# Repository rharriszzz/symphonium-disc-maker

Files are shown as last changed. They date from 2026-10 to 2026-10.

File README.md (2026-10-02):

# symphonium-disc-maker

Generate **exact SVG and DXF disc geometry** for the 20-note plastic-disc
mechanism used in a Mr. Christmas Animated Holiday Symphonium
(model 140-24021), plus simple printable/cuttable label sheets.

This repository begins as a reverse-engineering and arranging project.
The geometry is based on measurements, a 600 dpi scan of an original
*Unchained Melody* disc, a recording of the mechanism, and direct measurements
of the comb/plucker assembly.

## Status

**Experimental. Verify dimensions before paying for manufacturing.**

The most important current working values are:

- disc diameter: **7.000 in**
- original disc thickness: **0.020 in**
- prototype center hole: **0.200 in** (rounded from clear-edge scan fits)
- trusted metal center post: **0.1925 in**
- drive holes: **143**
- nominal drive-hole size: **0.100 in radial × 0.090 in tangential**
- drive-hole center radius: **3.373 in**
- note tracks: **20**
- note-hole diameter: **0.116 in**
- innermost track center radius: **0.94968 in**
- track pitch: **0.117921 in**
- provisional scale, inner to outer: **C4 through A6, white notes only**
- measured revolution time: about **28.126 s**

All of these live in `geometry.json` so they can be revised without changing code.

## Repository layout

```text
geometry.json                         measured machine geometry
examples/pachelbel_sampler.json      20-note, one-strike-per-tine sampler loop
examples/minimal_example.json        smallest arrangement example
src/symphonium_disc_maker/
    arrangement.py                   load/validate note events
    geometry.py                      track/note mapping
    svg.py                           exact printable/vector disc
    dxf.py                           manufacturing DXF
    labels.py                        label sheet generator
    cli.py                           command-line interface
tests/                               geometry and file-generation tests
docs/MEASUREMENTS.md                 provenance and open questions
```

## Installation

From the repository root:

```bash
python -m venv .venv

# Windows PowerShell
.venv\Scripts\Activate.ps1

# bash / macOS / Linux / WSL
source .venv/bin/activate

pip install -e .
```

## Make the Pachelbel sampler disc

Validate:

```bash
symphonium-disc validate examples/pachelbel_sampler.json
```

Generate an annotated SVG:

```bash
symphonium-disc svg examples/pachelbel_sampler.json \
  -o output/pachelbel_sampler.svg
```

Generate a manufacturing DXF in millimeters:

```bash
symphonium-disc dxf examples/pachelbel_sampler.json \
  -o output/pachelbel_sampler.dxf
```

The DXF contains only cut geometry: outside circle, center hole, 143 drive
holes, and music-note holes.

## Arrangement format

```json
{
  "title": "Example",
  "revolution_seconds": 28.126,
  "events": [
    {"time_seconds": 0.0, "note": "C5"},
    {"time_seconds": 0.7, "note": "E5"},
    {"time_seconds": 1.4, "note": "G5"}
  ]
}
```

`track` may be supplied instead of `note`.

The disc encodes **note onset**, not conventional note duration.

SVG and DXF show the **printed/top face**. Chronological holes proceed
clockwise around that stationary design, matching the reported counterclockwise
rotation during playback. Positive polar angles are counterclockwise from
the right (+X). `--start-angle` sets an arbitrary layout phase (default 230°),
not a measured reader angle. See the
[rotation follow-up](docs/CODEX_FOLLOWUP_ROTATION_CENTERPOST.md) for the evidence.

## Labels

Generate an 8.5 × 11 inch SVG sheet containing 20 circular labels:

```bash
symphonium-disc labels \
  --title "PACHELBEL" \
  --subtitle "Canon — sampler disc" \
  -o output/pachelbel_labels.svg
```

The label output is intended for a print-and-cut device such as a
BossKut Gazelle, Silhouette, Cricut, or similar machine.

The default 1.50-inch center label stays clear of the music holes. Use
`--mode print` for text only and `--mode cut` for circles only; `combined`
is the default paper fitting preview. The CLI checks the label diameter
against the innermost music holes and reads the center hole from `geometry.json`.
See [the label workflow and Gazelle findings](docs/LABELS.md) for examples,
alignment limitations, and the CUTOK driver investigation.
The [latest conversation discoveries](docs/CHATGPT_LATEST_DISCOVERIES.md)
confirm the disk geometry and update the Windows 11 / Mac Gazelle setup path.

A [printable fitting PDF](prototype_pack/label_fit_test.pdf) is ready for a
plain-paper test at 100% scale. It has a one-inch calibration ruler and
1.50-inch circles. The [prototype pack](prototype_pack/README.md) also contains
the cutting DXF and supplier drafts. These files are prepared for review;
supplier quotes and physical fit are still pending.
Separate [Xometry](supplier_packages/xometry_quote.zip) and
[SendCutSend](supplier_packages/sendcutsend_quote.zip) quote ZIPs now package
the cutting DXF, a dimensioned reference PDF and each company's request.
See [the delivery instructions](supplier_packages/README.md).
For a step-by-step plan with clickable links and Windows folder paths, read
`docs/NEXT_STEPS.md` or run `cat docs/NEXT_STEPS.md` in the repository terminal.

To make PDF labels, install `pip install -e '.[print]'` and choose a `.pdf`
output filename. Add `--calibration` for a paper fitting test. SVG and DXF
exporting still need no third-party runtime dependencies.

## Manufacturing notes

For services such as SendCutSend or Xometry:

- use the generated **DXF**;
- keep manufacturing artwork separate from labels and annotations;
- upload at **1:1 scale**;
- this project defaults to **millimeters** in DXF to avoid unit ambiguity;
- check quoted minimum feature size and material availability before ordering.

The original disc is approximately 0.020 inch thick. Material choice remains
an active experiment.

See [the prototype ordering notes](docs/ORDERING.md) for current supplier
options, draft inquiries, and the measurements to resolve before paying.
The prototype center-hole nominal is now 0.200 inch, rounded from approximately
0.198-inch clear-edge scan fits and consistent with the less certain 0.1995-inch
plastic-hole reading. The trusted metal post measures 0.1925 inch.
The nominal hole gives 0.0075 inch diametral clearance;
supplier tolerances and finished fit need checking. The corrected drive ring
has bridges as narrow as 0.05602 inch. Supplier tolerances and material behavior
still need confirmation.

The [conversation handoff](docs/CODEX_HANDOFF.md) supplies the scan-derived
drive-hole orientation. Both exporters rotate the openings around the ring.
The first material candidates are Xometry's 0.020-inch clear PETG and
SendCutSend's 0.030-inch clear polypropylene; their playback behavior remains
to be tested.

The [original scan and audio check](docs/REFERENCE_CHECK.md) independently
supports the drive-hole orientation and playback direction. It includes a
reproducible analysis script, a calibrated overlay, and detected-hole tables.
Opposite-quadrant edge comparisons distinguish scanner shadows from the
slightly rectangular openings and supply the current prototype dimensions.
Optional analysis dependencies can be installed with `pip install -e '.[analysis]'`.

The follow-up checks align all 143 drive openings and compare 22 starting
pitches. The rectangular shape and global C4–G6 occupied-track map hold across
the independent checks; track 20's A6 remains inferred until the sampler plays it.

## Next steps

- test the scan-derived radial and tangential drive-hole sizes on a prototype;
- cut the 20-note Pachelbel sampler;
- record isolated real tines;
- refine the playable pitch map and rotation timing;
- add MIDI/MusicXML import and arranging helpers;
- add disk PDF previews;
- add optional registration marks for print-and-cut label workflows.

## License

MIT.

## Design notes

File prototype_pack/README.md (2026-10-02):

# Pachelbel prototype pack

Prepared for a first fit/playback test. No quote or order has been submitted.
The same cutting geometry is intended for both supplier/material experiments.

## Files to use

- **`pachelbel_cut_mm.dxf`**: attach only this file for cutting. Confirm the
  quote preview shows a 177.800 mm outside diameter, 143 rotating rectangular
  drive openings and 20 round music holes. It contains 22 circles and 572 lines.
- `pachelbel_preview.svg`: annotated top-face inspection preview; guides and
  note names are not cutting geometry. Later attacks proceed clockwise.
- `xometry_inquiry.txt` and `sendcutsend_inquiry.txt`: supplier-specific drafts
  to review with the DXF. Quantity one each is proposed; price and fit are unknown.
- **`label_fit_test.pdf`**: print on plain US Letter paper at actual size / 100%,
  disabling Fit and Shrink. Measure the one-inch ruler and a 1.50-inch circle,
  then hand-cut one label and its 0.200-inch center opening. Check it on the original
  disk before using adhesive stock. This test can proceed without a cutter.
- `labels_print.pdf` and `labels_print.svg`: printing artwork without cut lines.
- `labels_cut.svg`: outer circles and center holes for cutter import.
- `labels_combined.svg`: artwork and outlines for inspection. All label files
  share the same 20-label layout; automatic print-to-cut registration is not provided.
- `recording_sequence.csv`: one attack per track, in time order, with expected
  pitches to test. Align a recorded cycle by its opening C6 attack; the layout
  phase is arbitrary and does not identify the mechanical reader position.
- `preflight.json`: calculated positive nominal clearances. Supplier tolerances,
  material behavior, thickness clearance and center-post fit remain unverified.
- `geometry.json`, `arrangement.json`, `manifest.json`: exact inputs and file
  hashes for identifying this version. Regenerate after changing the geometry.

The proposed materials are Xometry clear PETG at 0.020 inch and SendCutSend
clear polypropylene at 0.030 inch. Confirm material/process availability,
small-feature tolerances, quantity, shipping and total price before paying.
The original disk is 0.020 inch thick; extra thickness in polypropylene needs
a mechanism-clearance check. Retain the 0.200-inch prototype center-hole nominal for this test.
The metal post measures 0.1925 inch (4.8895 mm).
The prototype center hole has only 0.0075 inch (0.1905 mm) diametral clearance.
Please confirm finished-hole tolerances preserve clearance over this post.

Test the manufactured disk without a label first. Record at least two revolutions,
identify the supplier/material, and compare all 20 attacks with the sequence.
Attacks are only 1.4063 seconds apart: acoustic decay can overlap,
so this pack does not guarantee isolated clean samples. Track 20's A6 is inferred
until it is actually heard; tracks 18 and 19 had just one reference attack each.

## Regeneration

From the repository root, with the project and its `print` extras installed:

```bash
python scripts/build_prototype_pack.py --output prototype_pack
```

The builder calculates nominal clearances and checks DXF entity counts.
The source tests check rotated dimensions, units, playback direction and PDF scale.

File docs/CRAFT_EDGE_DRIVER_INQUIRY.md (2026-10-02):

# Craft Edge Gazelle driver inquiry

Draft only; not sent. Use the
[Craft Edge support form](https://www.craftedge.com/support/support_form.php)
if the connected-device check establishes that a Windows driver is needed.
Add the actual USB hardware IDs from that check when available.

**Subject:** BossKut Gazelle / CUTOK printer driver for Windows 11 x64

I own a BossKut Gazelle and want to cut small circular paper labels from SVG
files. My computer runs Windows 11 Home x64, build 26200. Sure Cuts A Lot 6.085
is already installed.

Your Gazelle setup guide requires a CUTOK printer driver on Windows, but the
linked CUTOK-hosted downloads are unavailable. Can you provide a current
official package or setup procedure for the Gazelle on Windows 11 x64?
Please confirm the supported hardware IDs and any model-specific requirements.
Hardware IDs have not yet been captured; I can supply them after checking USB
enumeration with the cutter connected and powered on.

Windows 10 is not an option. My fallback is an Apple Silicon Mac. Your guide
says no separate Mac driver is required; can you confirm the current Gazelle
connection procedure and any macOS or USB-adapter requirements?

After basic cutting works, I also want to align printed SVG label artwork with
the cut outlines. The installed Gazelle help includes a laser-to-blade offset
setting. Which SCAL edition and registration procedure should I use for this
cutter? I would like to verify USB communication, physical cut scale and
printed-label alignment before buying a license.

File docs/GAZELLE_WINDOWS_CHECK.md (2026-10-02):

# Gazelle Windows connection check

Checked October 1, 2026, Eastern time (October 2, 03:46 UTC).
The [read-only PowerShell diagnostic](../scripts/inspect_gazelle_windows.ps1)
was run on the Windows host. Its [JSON results](data/gazelle_windows_check.json)
record the observations and limits. No software or drivers were installed,
and no device settings were changed.

## Observed on this computer

- Windows 11 Home, build 26200, **x64**.
- **Sure Cuts A Lot 6.085 is already installed**, according to its uninstall
  registry entry. License/trial status and actual cutting have not been checked.
- The existing `SetupSureCutsALot_6_085_64bit.exe` download reports a **Valid**
  Windows Authenticode signature from **Craft Edge Inc**. Its SHA-256 is in
  the JSON report. A valid software signature does not establish Gazelle
  driver availability or working cutter communication.
- Among 247 present Plug and Play entries, none matched Gazelle, BossKut,
  CUTOK, DC330, generic USB printing support, USBPRINT, or the selected
  unknown/problem USB device criteria.
- No bound driver matched the Gazelle/CUTOK/DC330 names. This is not a search
  of the entire driver store and does not prove that a suitable package is absent.

The installed Craft Edge application folder was also checked for filenames
containing Gazelle, CUTOK or DC330, and for INF/CAT files. Only Gazelle help
assets matched; no driver package was found by this limited filename search.
The Gazelle-specific help includes a manual laser-to-blade offset setting.
This is a useful alignment lead, not a verified registration procedure.

## Immediate next action

The user plans to connect the Gazelle later, possibly the next morning. This
hardware check is deferred while supplier disk packages are prepared.

Connect the Gazelle by USB to this Windows computer and power it on, then
repeat the diagnostic to capture the device name, hardware IDs and driver status.
The empty candidate list alone cannot distinguish a disconnected or powered-off
cutter from a cable/port problem or an unexpectedly named device.

After the device appears, use those IDs to determine whether a suitable driver
is already bound. Craft Edge's [Gazelle setup guide](https://www.craftedge.com/tutorials/gazelle/setup.php)
describes the Windows CUTOK printer connection and SCAL's USB / Auto settings.
If a driver is needed, the [prepared Craft Edge inquiry](CRAFT_EDGE_DRIVER_INQUIRY.md)
already includes the confirmed Windows architecture and installed SCAL version.
It has not been sent. The fallback remains the Apple Silicon Mac.

SCAL does not need to be downloaded or installed again to reach this step.
Once communication works, test a simple paper circle at the correct scale;
then establish printed-label alignment. The existing
[label fitting PDF](../prototype_pack/label_fit_test.pdf) can also be printed
and hand-cut independently of the Gazelle connection.

## Repeat the check

From Windows PowerShell in the repository:

```powershell
powershell.exe -NoProfile -NonInteractive -File .\scripts\inspect_gazelle_windows.ps1
```

From WSL on this machine:

```bash
powershell.exe -NoProfile -NonInteractive -File '\\wsl.localhost\Ubuntu\home\rharris\git\symphonium-disc-maker\scripts\inspect_gazelle_windows.ps1'
```

JSON is written to stdout. `-InstallerPath` optionally checks an existing
installer's hash and signature without running it. Generic USB printer
candidates can be unrelated equipment; identify the Gazelle from the change
when it is connected before drawing conclusions about any candidate.

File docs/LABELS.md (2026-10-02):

# Small center labels and BossKut Gazelle setup

Use a **1.50-inch circular center label** that leaves the music and drive holes
uncovered. At the current dimensions its edge is 0.14168 inch (3.5987 mm)
inside the nearest music-hole edge. The largest circle that would just touch
that hole ring is 1.78336 inches; the CLI rejects labels at or above that size.
Leave room for cutting and placement error when choosing a size.

The label center-hole diameter defaults to `geometry.json`. The current
0.200-inch value is a rounded prototype nominal from approximately 0.198-inch
clear-edge scan fits, consistent with the less certain 0.1995-inch inside-jaw
reading of the plastic hole. The trusted metal post is 0.1925 inch.
Finished fit still needs testing, as described in
[the ordering notes](ORDERING.md). `--center-hole` allows a larger
label opening without changing the manufacturing geometry. A paper fitting
test should establish the final label opening.

## Generate printing artwork and cutting outlines

The ready-to-print [paper fitting PDF](../prototype_pack/label_fit_test.pdf)
has a US Letter page, 20 labels, and a one-inch calibration ruler. It can be
printed from Windows 11 or a Mac and hand-cut while the Gazelle connection
is unresolved. The [printing PDF](../prototype_pack/labels_print.pdf) contains
only label text. Both are in [the prepared prototype pack](../prototype_pack/README.md).

Run these commands from the repository root. All three sheets share the same
20-label layout on US Letter paper. Text sits above and below the center hole.
Long lines use a smaller font; inspect them before printing.

```bash
PYTHONPATH=src python3 -m symphonium_disc_maker.cli labels --title PACHELBEL --subtitle "Canon sampler" --mode combined -o output/pachelbel_labels.svg
PYTHONPATH=src python3 -m symphonium_disc_maker.cli labels --title PACHELBEL --subtitle "Canon sampler" --mode print -o output/pachelbel_labels_print.svg
PYTHONPATH=src python3 -m symphonium_disc_maker.cli labels --title PACHELBEL --subtitle "Canon sampler" --mode cut -o output/pachelbel_labels_cut.svg
```

- **Combined** contains the artwork and circles for inspecting the layout or
  printing a paper test to cut by hand.
- **Print** contains only the text. There are no printed cut lines.
- **Cut** contains only the outer circles and center holes. Import this for
  cutting outlines, so the cutter does not cut the letters.

For a new PDF, install the optional printing dependencies and use a `.pdf`
output filename:

```bash
pip install -e '.[print]'
PYTHONPATH=src python3 -m symphonium_disc_maker.cli labels --title PACHELBEL --subtitle "20-tine sampler" --calibration -o output/label_fit_test.pdf
PYTHONPATH=src python3 -m symphonium_disc_maker.cli labels --title PACHELBEL --subtitle "20-tine sampler" --mode print -o output/labels_print.pdf
```

PDF and SVG share the same layout calculations and physical dimensions.
PDF embeds DejaVu Sans for portable text rendering; SVG requests Arial or a
sans-serif fallback. The paper-test PDF adds the ruler and printing instructions
outside the label positions. `--calibration` is a PDF-only option. A raster
verification at 144 dpi confirms the 1.50-inch circle and one-inch ruler; the
PDF page is exactly 612 × 792 points. Printer settings still determine the
physical result, so measure the printed ruler before fitting a label.

`--rows`, `--columns`, `--diameter`, and `--center-hole` are adjustable.
This is a layout for full-sheet adhesive stock, not a verified template for
any brand of precut labels. Unsupported sizes and overlapping layouts are
rejected before a file is written.

Print at actual size / 100%, with page fitting disabled. Measure an outer
circle on the combined paper test: it should be 1.50 inches (38.10 mm).
Check the label on the original disk before using adhesive stock. A hand-cut
paper prototype allows label work to continue while the cutter is unresolved.

The separate files do **not** provide automatic print-to-cut registration.
Cutter imports may reposition artwork, discard the page origin, or rescale it.
Keep both files at the same scale and origin in the cutting software, then use
that software's supported alignment procedure. Do a plain-paper test before
cutting a printed adhesive sheet. Device-specific registration marks are not
yet implemented or verified for the Gazelle.

## Gazelle software and driver findings

Checked October 1, 2026. Craft Edge currently lists BossKut Gazelle among the
cutters supported by [Sure Cuts A Lot 6](https://www.surecutsalot.com/software/software_scal.php).
The software lists Windows 11 support. Craft Edge's
[product page](https://www.craftedge.com/products/products_scal.php) also lists
native Apple Silicon Mac versions. These are software capabilities; connection
to this particular Gazelle has not yet been demonstrated.
Its [official downloads page](https://www.craftedge.com/download/downloads.php)
provides the starting point for software evaluation.

This does not resolve Windows driver availability. Craft Edge's
[Gazelle setup guide](https://www.craftedge.com/tutorials/gazelle/setup.php)
specifies a **CUTOK printer driver** on Windows, with the device appearing as a
CUTOK printer and cutting connection set to USB / Auto. This is a different
driver path from the generic FTDI serial drivers used by some other cutters.
The guide says a Mac does not need a separate driver, but that is not a test
of this particular Gazelle on a current Mac.

The CUTOK-hosted resources are unavailable for this workflow. The
[latest handoff](CHATGPT_LATEST_DISCOVERIES.md) confirms the user's dead-link
experience; the old URLs are retained below as historical references only.
A current official Windows 11-compatible Gazelle/CUTOK driver download remains
**unverified**. Use Craft Edge's live downloads and support pages for the active
setup path.

The [Windows host check](GAZELLE_WINDOWS_CHECK.md) now confirms **Windows 11
Home x64** and an existing **SCAL 6.085** installation. No candidate cutter/USB
printer appeared in the present-device check; connection and power need to be
confirmed before deciding that a driver is missing. **Windows 10 is excluded**.
A Mac is the fallback if the Windows 11 connection cannot be established.
The latest handoff reports an Apple Silicon Mac; its macOS version and any
surviving original Gazelle installer remain unknown.

1. Connect and power on the Gazelle to inspect its Windows 11 enumeration in
   Device Manager and Devices and Printers. Record its device name, whether it
   appears as CUTOK/DC330 or an unknown USB device, and hardware IDs. This
   identifies the device; it does not establish that an unknown device can cut.
   Record the Windows architecture and any surviving original installer.
2. Use the installed SCAL 6.085 for evaluation; its license/trial status has
   not been checked. If Windows already has
   a working CUTOK printer driver, use the documented USB / Auto connection
   and try a small scrap-paper circle. Craft Edge's guide expects a driver
   before the cutting connection is made; the enumeration check above is
   diagnostic when that historical driver download is unavailable.
3. If the Windows driver is missing, ask
   [Craft Edge support](https://www.craftedge.com/support/)
   whether they can provide the Gazelle CUTOK driver and confirm support for
   Windows 11 on that architecture. Include the USB device's hardware IDs
   and model information. The [prepared inquiry](CRAFT_EDGE_DRIVER_INQUIRY.md)
   includes the confirmed Windows architecture and SCAL version; it has not been sent.
4. If Craft Edge cannot establish a working Windows 11 path, evaluate the
   Apple Silicon Mac using the SCAL trial. Their setup guide says no separate
   Mac driver is needed. Verify actual USB communication and a correctly
   scaled paper cut before buying a platform-specific license. SCAL trial cuts
   include extra watermark lines, according to its
   [FAQ](https://www.craftedge.com/support/faq/faq_surecutsalot4.php).
5. After simple cutting works, confirm the chosen software edition supports
   the Gazelle alignment workflow needed for printed labels. Cutter support
   and print-and-cut registration support are separate questions.

Third-party CUTOK/DC330 mirrors remain research leads, after the existing
Windows driver, Craft Edge support, and Mac routes. No mirrored package has
been verified or installed. If one is evaluated later, preserve and hash it,
inspect its INF/CAT files, hardware IDs, architecture and signatures, and scan
it before installation. Do not disable signature enforcement to force an
unknown driver. This mirrors the latest handoff's revised recommendation.

Automatic registration can wait: fit a plain-paper label, prove simple cutting
at the correct scale, then establish the actual Gazelle/SCAL alignment procedure
before adding device-specific marks. The existing print and cut files use the
same page origin and physical scale.

## Historical references — currently unavailable

These CUTOK-hosted URLs appeared in earlier research. They are historical
references, with no verified usable download, and are excluded from the active
setup workflow:

- `https://www.cutok.com/Support.htm`
- `https://www.cutok.com/down/Manual.pdf`
- `https://www.cutok.com/down/cutok_Signed.rar`

## Draft question for Craft Edge

The [current prepared inquiry](CRAFT_EDGE_DRIVER_INQUIRY.md) includes the
confirmed Windows 11 x64 and SCAL 6.085 details. The generic draft below is
retained for reference; neither draft has been sent.

> I own a BossKut Gazelle and want to cut small printed paper labels from SVG
> artwork. My computer runs Windows 11 [x64 or ARM64]. Your Gazelle setup
> guide requires a CUTOK printer driver on Windows, but the linked download
> is unavailable to me. Can you supply the original driver or a current
> official download and confirm compatibility with Windows 11 on that
> architecture? Windows 10 is not an option. A Mac is my fallback; can you
> confirm whether the Gazelle works without a separate driver on current
> macOS, including any Apple Silicon limitations? Also, which SCAL
> edition supports printed-label alignment with the Gazelle, and what
> registration procedure does it use? I would like to verify connection and
> alignment before purchasing software.

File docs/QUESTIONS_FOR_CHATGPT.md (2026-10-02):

# Findings and questions for the original ChatGPT conversation

Date: October 1, 2026. Repository: `rharriszzz/symphonium-disc-maker`.
Initial implementation and evidence are in commit `4246149` on `main`;
later verification and current center-hole corrections are recorded below.

The [latest discoveries handoff](CHATGPT_LATEST_DISCOVERIES.md) has now been
imported verbatim and read in full. It confirms the current geometry and corrected
photo identities. Questions 1 and 2 and the photo-identity question are closed.
The main remaining hardware/software uncertainty is a demonstrated Gazelle
connection on Windows 11 or the reported Apple Silicon Mac. CUTOK-hosted links
are historical unavailable references; the active workflow is in [LABELS.md](LABELS.md).

Please review this note alongside your original conversation and supporting
material. Your two handoff documents provided enough information to start;
the original scan and recording are now accessible locally. We do not need
another general summary. The specific questions below would help resolve the
remaining uncertainties.

## What Codex checked and changed

- The original 5100 × 6600 scan has approximately 600 dpi metadata. Local
  detection finds **143 drive holes, 145 music holes, and one center hole** at
  two brightness thresholds. Music holes occupy tracks 1–19 on this song.
- Drive-hole sides follow the local **radial/tangential axes**. Both SVG and
  DXF now rotate each opening accordingly.
- Both exporters use the **printed/top-face view** and place chronological
  notes clockwise: `start_angle - 360 * time / revolution_seconds`.
  The default 230° remains an arbitrary layout phase.
- Independent scan/audio comparison favors decreasing-angle chronological
  order by approximately **3.89×** at 28.126 seconds per revolution, and favors
  it at every tested period from 28.08 to 28.16 seconds. These are descriptive
  onset scores using the provisional pitch map, not probabilities or a full
  transcription.
- The user corrected the trusted metal post to **0.1925 inch** and the less
  certain plastic-hole inside-jaw reading to **0.1995 inch**. Independent
  clear-edge scan fits give approximately **0.198 inch**. The prototype uses
  a rounded **0.200-inch hole**; the earlier 0.2085 post and 0.196 hole values
  are superseded. A retaining-head explanation is no longer needed.
- Labels default to **1.50-inch circles**, leaving 0.14168 inch of radial
  clearance to the innermost music-hole edge. Separate printing and cutting
  SVGs are available; automatic cutter registration is still unresolved.
- The proposed supplier experiments remain Xometry **0.020-inch clear PETG**
  and SendCutSend **0.030-inch clear polypropylene**. Draft inquiries and
  manufacturing files are prepared locally. **No inquiry, quote request, or
  order has been submitted.**
- Automated checks cover SVG/DXF agreement, rotated drive openings,
  playback direction, legacy square geometry, label layout, PDF scale,
  nominal post clearance and synthetic shadow recovery.

## Updated drive-hole dimensions: please review independently

The initial 0.095-inch square was an average working value from the reported
0.09–0.10-inch readings. The user suggested comparing opposite holes to
separate shadows from geometry. That was useful: the shadow stays downward
in scanner coordinates while the local radial/tangential axes rotate.

The local analysis measures edges **across the shadow**: radial dimensions
at the left and right of the disk, tangential dimensions at the top and
bottom. Groups within 10° of the cardinal positions give:

| Measurement | Holes | Median edge spacing | Calibrated inches |
| --- | ---: | ---: | ---: |
| Left/right radial | 16 | 59.625 pixels | 0.09909 |
| Top/bottom tangential | 15 | 53.000 pixels | 0.08808 |

Opposite group medians agree within 0.4 pixel. Varying smoothing from 0.5 to
1.5 pixels changes individual group medians by at most 0.25 pixel relative
to the 1-pixel setting. The axis difference is 6.625 pixels. Because the ring
has an odd number of holes, the selected opposite examples are approximately
179° apart rather than exactly 180°.

The method uses grayscale edge gradients across median central strips,
rather than treating the bright interior alone as the whole opening. Scale
is **601.754 pixels/inch**, calibrated to the measured 7-inch outer diameter.
Allow approximately 1–2 pixels for optical boundary choice; that is a practical
allowance, not a calibrated confidence interval. The openings appear slightly
rectangular, with rounded corners.

The current prototype nominals are therefore **0.100 inch radial × 0.090 inch
tangential**, recorded separately in `geometry.json`. At the unchanged
3.373-inch center radius, they give approximately **0.07670 inch outer
clearance** and **0.05602 inch minimum bridge**. The outer clearance agrees
closely with the user's approximately 0.0760-inch measurement.

**Question 1 — drive rectangle interpretation: resolved.** The independent
ensemble and opposite-edge methods agree, and the latest handoff confirms
keeping 0.100 inch radial × 0.090 inch tangential. No additional response is
needed to select the first-prototype drive openings.

The [paired crops and edge profiles](figures/drive_opposites.png),
[full method and results](REFERENCE_CHECK.md), and
[reproducible script](../scripts/check_reference.py) are committed in the repo.
The full report and detected-hole tables are generated locally under
`output/reference_check/`; the original scan and recording remain outside Git.

## Existing supporting material that would help

**Question 2 — center post: resolved by corrected measurements.** The user
trusts the metal-post reading of 0.1925 inch. Both the 0.1995-inch plastic-hole
reading and the independent scan estimate put the hole above that diameter.
The request for a missing post photograph is withdrawn; no additional
center-post material or repeated caliper measurements are needed to prepare
the prototype. Please do not carry the old 0.2085/0.196 mismatch or the inferred
retaining-head explanation into further recommendations.

**Question 3 — pitch mapping and prior analysis:** Was the C4–A6 diatonic
inner-to-outer map independently established for each tine, or assumed for
the sampler? If you have retained isolated-tine recordings, pitch tables,
detected-hole coordinates, or the original scan/audio analysis scripts,
please identify and provide those existing artifacts. State which pitches
were measured and which were inferred. The new audio check supports direction
but does not independently establish every tine's pitch.

**Question 4 — Gazelle:** Do you have a surviving original BossKut Gazelle
installer, CUTOK printer-driver package, or a verified working vendor download
from the earlier research? The user's preference is **Windows 11 first, Mac
otherwise; never Windows 10**. Local research recorded in
[the label notes](LABELS.md) points to Craft Edge's CUTOK printer-driver setup;
the linked CUTOK download was inaccessible. A supported-cutter listing alone
does not establish Windows 11 driver availability. Please supply the original
package/source if it exists and distinguish verified OS compatibility from
an untested suggestion. No working Windows 11 or current Mac connection has
yet been demonstrated. The latest handoff reports an Apple Silicon Mac;
The [Windows host check](GAZELLE_WINDOWS_CHECK.md) now confirms Windows 11 Home
x64 and an existing SCAL 6.085 installation; the Mac's OS version remains unknown.
CUTOK-hosted
downloads are historical unavailable references, so the current priority is
Windows enumeration, the SCAL trial, Craft Edge support and Mac fallback.

## Requested reply

If replying again, prioritize the still-unresolved Gazelle installer question;
independent comments on drive boundaries or isolated-tine evidence are welcome.
The center-post question is resolved. Please put any reply in a Markdown file,
preferably `docs/CHATGPT_RESPONSE_FOLLOWUP.md`, with links or supporting files where
available. Explicitly mark unavailable artifacts and unverified conclusions.
The user can pass the reply and attachments back to Codex. Preserve the
original handoff documents as historical context; current implementation
and prototype dimensions are described above and in `geometry.json`.

## Follow-up after importing the response package

The earlier response is saved as [CHATGPT_RESPONSE.md](CHATGPT_RESPONSE.md), with the
[provided profile CSV](data/aligned_drive_profiles.csv). Four JPEGs were
extracted to local `reference_material/` and viewed directly. The latest handoff
now confirms their corrected identities, closing that question. The files show:

- `IMG_3359.jpeg`: the disk installed, with the center post visible through it.
- `IMG_3360.jpeg`: the loose disk on a wooden surface, rather than an installed view.
- `IMG_3361.jpeg`: the comb and plucker assembly; no center post is visible.
- `IMG_3362.jpeg`: the drive motor/gears and adjacent pluckers, with the disk removed from the drive area.

Your response describes `IMG_3361.jpeg` as the best center-post photograph
and `IMG_3362.jpeg` as an installed disk at the gear. Those descriptions do
not match these attachments; the latest handoff corrects those descriptions.
The earlier request for an unobstructed post photograph is
withdrawn following the user's corrected 0.1925-inch measurement; the photo
identity discrepancy no longer blocks the dimensional work.

## Local verification completed after the response

The independent checks now reproduce the main shape and pitch-map conclusions:

- The fresh 143-hole aligned average gives an aspect ratio of 1.1238 at
  threshold 150; your supplied CSV gives 1.1250. Outer ellipse axis differences
  are 0.0937–0.1139% over three boundary thresholds.
- Among 22 consecutive-white-key starts from C2 through C5, C4 ranks first
  with 4096/8192-sample FFTs, with or without harmonic weighting, and in both
  complete recorded revolutions separately. It also wins when the second
  revolution is evaluated at phases fitted to the first.
- The map remains a global hypothesis under the consecutive-white-key
  assumption; track 20's A6 is inferred rather than independently heard.
- The prototype pack includes cutting geometry, supplier drafts, nominal
  clearance checks, recording order, and physical-size label PDFs.
- Sampler attacks are 1.4063 seconds apart. They may have overlapping decay,
  so please avoid describing them as guaranteed isolated clean tine samples.

## Center-hole correction after the user's latest measurements

The user finds the outside-jaw metal-post measurement much easier than using
the inside jaws on the small plastic hole. Treat 0.1925 inch as the trusted
post value and 0.1995 inch as the less certain original-hole reading.

The scan's downward shadow shrinks its apparent white opening. Independent
circle fits to the clear upper arc and opposed side arcs give 118.98 and
119.33 pixels at 1-pixel smoothing. Using the scan's 599.9988 dpi gives
0.19830 and 0.19888 inch; using the 7-inch outer-diameter calibration gives
0.19772 and 0.19830 inch. Both are consistent with the user's hole reading
within the practical optical boundary allowance. A full-perimeter fit includes
the lower shadow and underestimates the diameter.

The prototype and matching label openings now use **0.200 inch**, a rounded
test nominal, with **0.0075 inch diametral clearance** over the metal post.
The DXF, label PDFs/SVGs, supplier drafts and pack manifest have been regenerated.
Finished supplier hole tolerance still needs confirmation. See
[the annotated crop and method](REFERENCE_CHECK.md#center-hole-edges-and-post-fit)
and [the reproducible analysis](../scripts/measure_center_hole.py).

The [methods and full results](REFERENCE_CHECK.md) and
[prototype pack](../prototype_pack/README.md) are committed. No further general
summary is needed. The outstanding useful artifact is a surviving Gazelle/CUTOK
installer or verified download for the user's Windows 11 or Mac workflow.
The center-post photograph is no longer required.

## Supplier delivery packages prepared

Separate [Xometry](../supplier_packages/xometry_quote.zip) and
[SendCutSend](../supplier_packages/sendcutsend_quote.zip) packages now contain
the same audited cutting DXF, a dimensioned reference PDF and tailored quote
requests. The DXF has 165 closed contours: 143 drive openings and 22 circles.
The requests ask for the minimum finished center opening through the full
thickness, drive-hole position tolerances, corner rounding and stock thickness.
No additional AI response is needed to prepare the first quotes. Supplier
feasibility and finished-hole tolerance remain open; nothing has been submitted.
The user will connect the Gazelle later, so cutter work is deferred.

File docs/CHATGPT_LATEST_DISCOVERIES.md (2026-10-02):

# Latest discoveries and corrections for `symphonium-disc-maker`

Date: October 1, 2026  
Repository: `rharriszzz/symphonium-disc-maker`

This note is intended as the latest handoff back to Codex CLI. It should be read as
an update to, not a replacement for, the older handoff documents.

The main purpose is to record the newest corrections and conclusions that emerged
after the last round of repo work.

---

## 1. Center-hole / center-post values are now corrected

The earlier values:

```text
center hole: 0.196 in
center post: 0.2085 in
```

should no longer be used.

The current trusted measurements and scan result are:

```text
trusted metal post diameter:          0.1925 in
less-certain plastic-hole caliper:    0.1995 in
scan clear-edge center-hole estimate: about 0.198 in
prototype center-hole nominal:        0.2000 in
prototype diametral clearance:        0.0075 in
```

The user's outside-jaw measurement of the metal post is considered more reliable than
the inside-jaw measurement of the small plastic hole.

The scan's downward shadow makes a full-perimeter white-region fit underestimate the
hole diameter. Fits to clearer upper/opposed arcs give values near 0.198 in, consistent
with the user's ~0.1995 in hole reading.

### Consequence

The current prototype value:

```text
center_hole_diameter = 0.200 in
```

is appropriate.

Do not carry forward the older hypothesis that a 0.196-inch hole had to flex over a
0.2085-inch retaining head. That mismatch was caused by earlier measurements that have
now been superseded.

---

## 2. Corrected identities of the mechanism photographs

My earlier response mislabeled several of the four supplied JPEGs.

The correct descriptions are:

### `IMG_3359.jpeg`

- Disk installed in the machine.
- Printed/top face visible.
- Center post visible through the disk.
- Useful for normal installed orientation and overall mechanism relationship.

### `IMG_3360.jpeg`

- Loose disk on a wooden surface.
- Not an installed mechanism view.

### `IMG_3361.jpeg`

- Comb / tine / plucker assembly.
- Useful for counting the 20 note positions and their spacing.
- No useful center-post seating-neck view.

### `IMG_3362.jpeg`

- Drive motor/gears and adjacent pluckers.
- Disk removed from the drive area.
- Useful for observing that the drive tooth is smaller than the disk drive opening.

The center-post photograph issue no longer blocks prototype work because the corrected
post and hole measurements now give a normal positive clearance.

---

## 3. Drive openings: keep 0.100 in radial × 0.090 in tangential

The latest independent checks continue to support the rectangular interpretation.

Current best measurements from the scan:

```text
radial edge spacing:       ~0.09909 in
tangential edge spacing:   ~0.08808 in
```

Current prototype nominals:

```text
radial_size      = 0.100 in
tangential_size  = 0.090 in
```

### Independent support

A separate 143-hole local-coordinate averaging method gives essentially the same
radial/tangential aspect ratio as Codex's opposite-cardinal-hole grayscale-gradient
method.

The user's direct physical measurement of the outer radial clearance also supports
the 0.100-inch radial dimension:

```text
disk radius             = 3.500 in
drive center radius     = 3.373 in
half radial opening     = 0.050 in
predicted edge clearance= 0.077 in
measured clearance      ≈ 0.0760 in
```

Scanner X/Y scale anisotropy is only about 0.1%, far too small to explain the roughly
12% radial/tangential size difference.

### Conclusion

Keep:

```text
drive opening = 0.100 in radial × 0.090 in tangential
```

for the first prototype.

Treat these as prototype nominals, not final calibrated manufacturing tolerances.

---

## 4. Drive-opening orientation remains radial/tangential

This conclusion remains strong.

The 143 openings rotate with their polar position; their sides are approximately
aligned with the local radial and tangential axes.

The repo should continue to generate each rectangular opening rotated by the local
drive-hole polar angle.

Do not revert to globally axis-aligned rectangles.

---

## 5. Playback orientation and face convention remain unchanged

The confirmed convention is:

```text
CAD view:                        printed/top face
0 degrees:                       +X / right
positive mathematical angle:     counterclockwise
physical disk rotation, top view:counterclockwise
chronological event direction:   clockwise
```

Thus the event formula on top-face CAD is:

```python
angle = start_angle - 360.0 * time / revolution_seconds
```

The machine reads/plucks the disk from underneath, so the same physical motion appears
clockwise when viewed directly from below.

The current default:

```text
start_angle = 230 degrees
```

remains an arbitrary layout phase and has no measured mechanical significance.

---

## 6. Pitch map is better supported, but track 20 remains inferred

The current map is:

```text
track  1  C4
track  2  D4
track  3  E4
track  4  F4
track  5  G4
track  6  A4
track  7  B4
track  8  C5
track  9  D5
track 10  E5
track 11  F5
track 12  G5
track 13  A5
track 14  B5
track 15  C6
track 16  D6
track 17  E6
track 18  F6
track 19  G6
track 20  A6
```

The map is no longer just a convenient sampler assumption.

Independent scan/audio tests now show that, among tested consecutive-white-key starts,
the occupied tracks are best explained by:

```text
track 1 = C4
through
track 19 = G6
```

This conclusion survives:

- multiple FFT sizes;
- with and without harmonic weighting;
- each complete recorded revolution separately;
- second-revolution evaluation using phases fitted from the first.

### Remaining limitation

```text
tracks 18 and 19: only one physical hole each on Unchained Melody
track 20:         no hole on Unchained Melody
```

Therefore:

```text
track 20 = A6
```

remains inferred by continuation.

There is still no clean isolated-tine recording set and no trustworthy full MIDI
transcription of Unchained Melody that should replace the current reproducible
scan/audio analysis.

---

## 7. Pachelbel sampler: useful but not guaranteed to produce isolated samples

The sampler disk has:

```text
20 attacks
1 attack per provisional tine
28.126 s revolution
1.4063 s nominal attack spacing
```

It remains a very useful calibration/recording disk.

However, avoid calling the resulting sounds "guaranteed isolated tine samples."

Real music-box tines may ring longer than 1.4063 seconds, so neighboring decays may
overlap.

The safer description is:

> sparse calibration sequence with one known attack per tine and no simultaneous
> attacks

That is still much better than extracting overlapping notes from Unchained Melody.

---

# 8. Major Gazelle/CUTOK correction: treat all `cutok.com` material as unavailable

The user's `whois` check found no match for `WWW.CUTOK.COM`, and live attempts to load
the previously referenced CUTOK resources currently fail.

Therefore, for practical purposes:

> **Treat everything hosted on `cutok.com` as unavailable historical material.**

Do not rely on any of the following as current usable resources:

```text
https://www.cutok.com/Support.htm
https://www.cutok.com/down/Manual.pdf
https://www.cutok.com/down/cutok_Signed.rar
```

Even where those URLs were historically cited by users, they should now be considered:

```text
historical references only
not live setup dependencies
```

Do not tell the user that the official CUTOK manual or driver is currently accessible.

---

## 9. What remains currently verified for the BossKut Gazelle

Current Craft Edge material still supports these statements:

- Sure Cuts A Lot 6 lists **BossKut Gazelle** as a supported cutter.
- SCAL 6 supports **Windows 11**.
- Craft Edge has a live Gazelle setup page.
- That page says Windows uses a **CUTOK printer driver**.
- It says the Gazelle should appear as a CUTOK printer and SCAL should use USB / Auto.
- The setup page says Mac does not require a separate driver.

Current useful Craft Edge pages:

```text
https://www.craftedge.com/tutorials/gazelle/setup.php
https://www.surecutsalot.com/software/software_scal.php
https://craftedge.com/help/surecutsalot6/index.php
https://www.craftedge.com/download/downloads.php
https://www.craftedge.com/support/
```

### Important distinction

This verifies:

```text
SCAL 6 supports Windows 11
SCAL 6 supports BossKut Gazelle
Craft Edge expects a CUTOK driver on Windows
```

It does **not** verify that a current official Windows 11-compatible CUTOK driver
package is presently downloadable.

That is still unresolved.

---

# 10. Updated Gazelle recommendation

The active workflow should now be:

## Windows 11 first

1. Connect the Gazelle by USB.
2. Power it on.
3. Check:
   - Device Manager
   - Devices and Printers
4. Record:
   - device name;
   - whether it appears as CUTOK / DC330;
   - hardware IDs if Windows shows an unknown device.
5. Install the current **SCAL 6 trial** from Craft Edge.
6. If Windows already recognizes the device correctly, test a simple scrap-paper cut.

## If a Windows driver is missing

Ask **Craft Edge directly** for:

```text
BossKut Gazelle / CUTOK printer driver for Windows 11
```

Include:

```text
Windows architecture
USB hardware IDs
exact Gazelle model if known
```

Do not spend time chasing dead CUTOK URLs.

## If Craft Edge cannot provide a working Windows 11 driver

Switch to the **Mac path** rather than installing arbitrary driver packages.

Craft Edge's current setup says Mac does not need a separate driver.

The user has an Apple Silicon Mac, and current SCAL 6 supports Apple Silicon.

Use the SCAL trial first and verify direct USB communication before purchasing a
platform-specific license.

---

## 11. Third-party driver mirrors: downgraded recommendation

There are third-party CUTOK/DC330 driver listings that claim Windows 11 compatibility.

These may remain useful as **research leads**, but should not be recommended as the
default installation path.

For a printer/kernel-style driver, preferred order is now:

```text
1. Windows already has a usable driver
2. Craft Edge supplies a current package or procedure
3. Mac path
4. only then evaluate a third-party legacy driver package
```

If a third-party package is eventually considered:

- preserve the original download;
- compute SHA-256;
- inspect INF/CAT contents;
- check hardware IDs;
- verify architecture;
- check signatures where possible;
- scan before installation.

Do not disable Windows driver-signature enforcement simply to force an unknown package.

---

## 12. Print-and-cut / registration recommendation

Do not make automatic registration a prerequisite for continuing the project.

The repository already generates:

```text
labels_print.pdf / labels_print.svg
labels_cut.svg
label_fit_test.pdf
```

The immediate sequence should be:

1. test physical label size on plain paper;
2. prove simple Gazelle cutting at correct scale;
3. determine the actual registration/alignment procedure supported by the working
   Gazelle + SCAL combination;
4. only then add device-specific registration marks to the repository.

Until the actual cutter workflow is demonstrated, keep print artwork and cut geometry
separate and aligned to the same physical page origin/scale.

---

## 13. Recommended repo documentation updates

### `docs/LABELS.md`

Remove live-workflow dependence on `cutok.com`.

Any old CUTOK URLs should be moved to a section clearly labeled:

```text
Historical references — currently unavailable
```

The active setup should read:

```text
Windows 11
→ inspect enumeration
→ SCAL 6 trial
→ Craft Edge support for missing driver
→ Mac fallback if no working Windows path
```

### `docs/QUESTIONS_FOR_CHATGPT.md`

The following are now effectively closed:

- center-post mismatch;
- photo identity question;
- drive rectangle interpretation.

The principal remaining hardware/software uncertainty is:

```text
verified working Gazelle connection on a current OS
```

### `geometry.json`

The current values are appropriate:

```text
center hole: 0.200 in prototype nominal
center post: 0.1925 in trusted measurement
drive:       0.100 radial × 0.090 tangential
track map:   C4–A6, with track 20 inferred
```

---

# 14. Current state summary

## Strong enough for first physical prototype

- 7.000 in disk
- 0.020 in original thickness reference
- 0.200 in prototype center hole
- 0.1925 in trusted center post
- 143 drive openings
- 0.100 × 0.090 in drive opening
- radial/tangential drive orientation
- 20 note tracks
- ~0.117921 in track pitch
- top-face chronological direction
- C4→G6 well-supported for tracks 1–19
- A6 inferred for track 20
- Pachelbel sampler arrangement
- DXF/SVG prototype pack
- label print/cut files

## Still unresolved

- first real manufactured-disk fit and playback;
- actual supplier finished-hole tolerances;
- track-20 pitch by direct playback;
- repeated-note mechanical reset limit;
- real tine decay overlap;
- current working Gazelle connection under Windows 11 or macOS;
- current official Windows Gazelle/CUTOK driver package.

---

# 15. Bottom line for Codex

The most important newest correction is:

> **Do not rely on `cutok.com` at all. Treat it as gone/unavailable.**

The Gazelle workflow should now be:

```text
Windows 11 device enumeration
→ SCAL 6 trial
→ Craft Edge support if driver missing
→ Mac fallback
→ only then consider vetted legacy third-party driver packages
```

The current disc geometry work remains valid and is strong enough to proceed toward
a first prototype order.

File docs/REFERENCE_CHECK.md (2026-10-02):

# Original scan and audio verification

The original scan and recording were checked locally on October 1, 2026.
They support the corrected radial/tangential drive holes and clockwise
chronological note layout on the printed face. Comparing opposite drive holes
also resolves the earlier size uncertainty well enough to select prototype
nominals: **0.100 inch radial × 0.090 inch tangential**. These are scan-informed
dimensions for a fit test, rather than exact manufacturing tolerances.

## Supporting files

Both originals are accessible directly through WSL; they were not copied into Git.

- Scan: `/mnt/c/Users/rharr/OneDrive/Documents/img20261001_00272891.png`
- Recording: `/mnt/c/Users/rharr/Downloads/116 E Main St 15.m4a`

The scan is 5100 × 6600 pixels, RGB, with 599.9988 dpi metadata. The recording
is mono AAC at 48 kHz and approximately 59.968 seconds long. The report records
SHA-256 fingerprints of the source files and geometry used.

The subsequent [ChatGPT response](CHATGPT_RESPONSE.md) and its
[aligned-drive profile CSV](data/aligned_drive_profiles.csv) were imported
unchanged from `CHATGPT_RESPONSE_SYMPHONIUM.zip`. Both downloaded Markdown
copies and the archive's Markdown member were byte-identical. The response
reports a separate ensemble shape check and pitch-map comparison. Both have
now been checked independently with the original scan and recording, as
described below. Its four photos are
stored locally under `reference_material/`, with source hashes in
`reference_material/chatgpt_response_import.json`. Several photo descriptions
do not match the attachments; see the follow-up in
[the questions file](QUESTIONS_FOR_CHATGPT.md).

## Scan results

The script fits the outer boundary of the largest dark connected component,
then detects bright enclosed regions. With a grayscale disk threshold of 140
and hole thresholds of **both 150 and 170**, it finds:

- **143 drive holes**, each assigned to a distinct position in a regular ring.
- **145 music holes**, assigned to tracks 1 through 19.
- **One center hole**. Track 20 has no music hole on this reference song.

Hole centers, not printed graphics, supply the geometric comparisons.
Each hole's fourth complex moment estimates the orientation of these nearly
square openings modulo 90°. The radial/tangential orientation is substantially
closer than globally axis-aligned openings.

| Measurement | Hole threshold 150 | Hole threshold 170 |
| --- | ---: | ---: |
| Mean absolute radial/tangential orientation residual | 1.602° | 1.801° |
| Mean absolute globally axis-aligned orientation residual | 23.003° | 23.271° |
| Regular drive-ring angular RMS residual | 0.0381° | 0.0397° |
| Drive radius RMS difference from CAD | 0.00286 in | 0.00315 in |
| Music-hole radius RMS difference from assigned track | 0.00351 in | 0.00399 in |
| Maximum music-hole radius difference | 0.00759 in | 0.00878 in |

The fitted outer circle is centered at **(2396.327, 4361.877) pixels**, with a
radius of **2106.139 pixels** and a boundary RMS residual of 1.101 pixels.
Calibrating its diameter to the measured 7.000 inches gives **601.754 pixels
per inch**, approximately 0.29% above the nominal scan DPI. This chosen
calibration is explicit; it assumes the caliper diameter is correct.

The fitted radius differs from the earlier handoff's 2104.615-pixel value by
about 1.524 pixels. Different boundary thresholds include different amounts of
the edge shadow. In exploratory fits, raising the disk threshold from 140 to
180 changed the fitted radius to 2107.259 pixels. These are optical boundary
choices, not evidence that the physical disk changed size.

The selected scan calibration gives a mean drive-center radius of **3.37056
inches**, versus the CAD nominal 3.373 inches. Keep the working CAD nominal
pending physical tests rather than adjusting it from this threshold-dependent
measurement alone.

## Center-hole edges and post fit

The user corrected the trusted metal-post measurement to **0.1925 inch**.
The latest plastic-hole inside-jaw reading is **0.1995 inch**, with lower
confidence because the small opening is harder to measure. The older
0.2085-inch post value is superseded, resolving the apparent hole/post mismatch.

The center hole has a downward scanner shadow, and black printed artwork
surrounds it. The bright area alone is approximately 0.189 inch in equivalent
diameter and cannot be used as the physical opening diameter. Instead,
`scripts/measure_center_hole.py` samples outward grayscale gradients every 2°,
interpolated at 0.1-pixel intervals, from a 201 × 201 native-pixel crop.
It fits the clear upper arc and opposed side arcs independently. The side arcs
are within approximately 27° of horizontal, across the shadow. The upper fit
excludes the shaded lower arc; the fitted center is allowed to move rather than
being fixed to the shadow-displaced white-area centroid.

At 1-pixel gradient smoothing:

| Edges used | Diameter, pixels | At scan DPI, inches | At 7-inch disk calibration, inches | Radial residual RMS, pixels |
| --- | ---: | ---: | ---: | ---: |
| Clear upper arc | 118.981 | 0.19830 | 0.19772 | 0.193 |
| Opposed side arcs | 119.328 | 0.19888 | 0.19830 | 0.200 |
| Full perimeter, including shadow (diagnostic only) | 117.313 | 0.19552 | 0.19495 | 1.972 |

The two useful fits agree within 0.35 pixel. Changing smoothing from 0.5 to
1.5 pixels keeps upper-arc diameters within 0.08 pixel and side-arc diameters
within 0.06 pixel. The shadow-biased full-perimeter fit has roughly ten times
the residual and a smaller diameter. The low residual of the selected arcs
checks their consistency; it does not prove absolute optical accuracy.

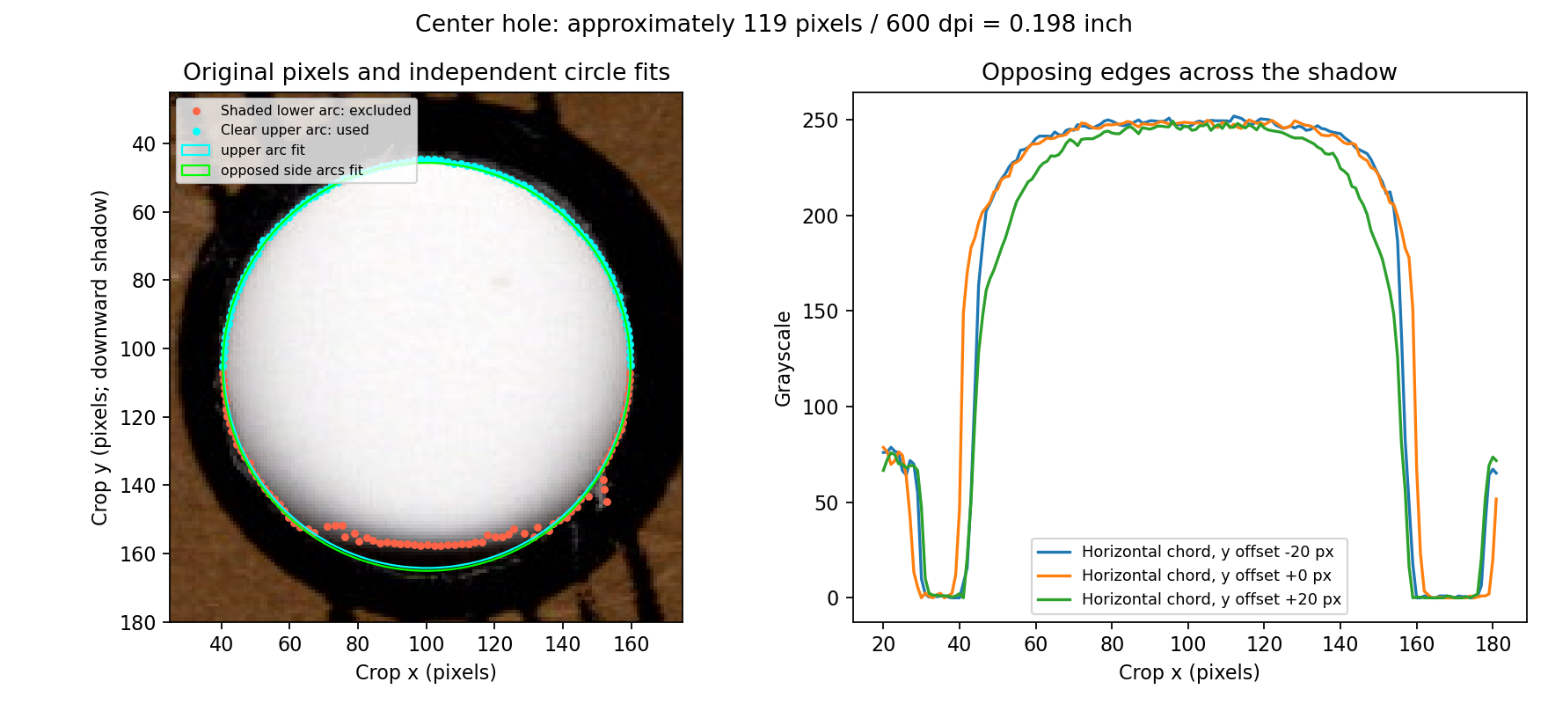
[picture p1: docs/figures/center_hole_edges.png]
Center-hole clear edges and horizontal profiles


The cyan circle is the upper-arc fit; green is the independent side-arc fit.
Red points show the rejected lower-edge measurements. The profiles on the right
cross opposite side edges at three heights. Their widths vary as circular chords
should, while the bottom shadow shrinks the apparent vertical opening.

The scan supports an opening of approximately **0.198 inch**, consistent with
the user's 0.1995-inch reading. Its 599.9988 dpi metadata and the 601.754 ppi
outer-diameter calibration differ by only about 0.0006 inch here. We retain
both scales because the outer-diameter calibration assumes the 7-inch reading
is exact. Allow approximately one pixel per optical edge, or **0.0033 inch on
diameter**, as a practical boundary allowance rather than a statistical
confidence interval. Interpolation does not add source resolution.

The first prototype now uses a rounded **0.200-inch center hole**, replacing
the earlier 0.196-inch nominal. This is a test dimension, not a four-decimal
measurement of the original. It gives **0.0075 inch diametral clearance**
(0.00375 inch per side) over the trusted metal post. Supplier finished-hole
tolerance and actual seating still need confirmation; no missing post photo
or additional caliper readings are needed to prepare the files.

The [committed center-hole report](data/center_hole_check.json) records source
fingerprints, both calibrations and all smoothing checks. A synthetic known-size
opening with a downward shadow verifies that the clear arcs recover its diameter
while the full-perimeter fit underestimates it.

Reproduce from the repository root with the optional analysis dependencies:

```bash
MPLCONFIGDIR=/tmp/symphonium-matplotlib PYTHONPATH=src python3 scripts/measure_center_hole.py \
  --scan /mnt/c/Users/rharr/OneDrive/Documents/img20261001_00272891.png
```

Outputs go to `output/center_check/`; neither the scan nor manufacturing inputs
are changed by the analysis.

## Opposite drive-hole edges and prototype dimensions

The original scan has enough resolution to distinguish the two drive-hole
dimensions. A bright-pixel mask alone discards the shaded part of an opening;
that was the limitation of the first local check, not of the supplied image.

Following the user's suggestion, compare top with bottom and left with right.
The shadow stays toward the bottom of the scanner image. In radial/tangential
coordinates it switches sides between opposite holes. Because there are an
odd **143** openings, none has an exactly opposite partner; the representative
holes are approximately 179° apart.

Measure edges **across** the shadow: radial width at the left and right of the
disk, and tangential width at the top and bottom. The script samples central
17-pixel strips along each local axis, interpolated at quarter-pixel intervals,
and finds opposing grayscale edge gradients after 1-pixel smoothing. This
sampling interpolates existing pixels; it does not increase source resolution.
Groups within 10° of each cardinal position give:

| Group | Axis measured across shadow | Holes | Median pixels | Inches |
| --- | --- | ---: | ---: | ---: |
| Right | Radial | 8 | 59.750 | 0.09929 |
| Left | Radial | 8 | 59.500 | 0.09888 |
| Top | Tangential | 7 | 52.750 | 0.08766 |
| Bottom | Tangential | 8 | 53.125 | 0.08828 |
| Left and right combined | Radial | 16 | 59.625 | **0.09909** |
| Top and bottom combined | Tangential | 15 | 53.000 | **0.08808** |

The opposite groups agree within 0.4 source pixels. Repeating with smoothing
of 0.5 and 1.5 pixels changes group medians by at most 0.25 pixel relative to
the 1-pixel result. The approximately **6.625-pixel** difference between axes
is substantially larger than those variations. The openings appear slightly
rectangular, with rounded corners; their size difference cannot be explained
by a fixed downward shadow alone.

Allow approximately 1–2 pixels (0.0017–0.0033 inch) for optical boundary
choice; this is a practical allowance, not a calibrated confidence interval.
Use **0.100 × 0.090 inch**, rounded prototype nominals consistent with the
earlier 0.09–0.10-inch caliper readings. `geometry.json` now records the two
axes separately, and SVG/DXF use them. The former 0.095-inch square was an
average placeholder. No further caliper measurement is needed to choose this
first prototype geometry; finished part fit still supplies the mechanical test.

With the unchanged 3.373-inch center radius, the nominal outer clearance is
**0.07670 inch**, close to the user's approximately 0.0760-inch measurement.
The minimum bridge between adjacent drive cutouts is **0.05602 inch**.

[The opposite-hole figure](figures/drive_opposites.png) shows native-resolution
crops enlarged without smoothing and the radial/tangential edge profiles.
A compact copy is retained with these notes; the full analysis output remains
local. `report.json` records the group
measurements, smoothing checks, and selected pair separations.

## Independent ensemble and ellipse checks

`scripts/verify_response.py` aligns all 143 openings into radial/tangential
coordinates and averages their grayscale patches. A fixed scanner shadow
rotates through local directions while the opening shape reinforces. Central
profile crossings give:

| Brightness threshold | Local radial width, pixels | Local tangential width, pixels | Local aspect ratio | Supplied CSV aspect ratio |
| --- | ---: | ---: | ---: | ---: |
| 130 | 55.292 | 49.565 | 1.1155 | 1.1151 |
| 150 | 53.788 | 47.861 | **1.1238** | **1.1250** |
| 170 | 52.529 | 46.200 | 1.1370 | 1.1370 |
| 190 | 51.174 | 44.736 | 1.1439 | 1.1497 |

The supplied CSV reproduces the threshold widths stated in the response.
Our fresh average gives closely agreeing shape ratios; absolute crossings
differ slightly with centering and detection choices. The crossing calculation
uses only the connected bright region containing zero. Neighboring drive
openings and outside paper at the profile ends do not enlarge the measured span.
These are bright-interior measurements, so retain the across-shadow dimensions
as the better basis for absolute prototype cut size.

A general conic ellipse fit to the outer boundary gives axis differences of
**0.0937%, 0.1091%, and 0.1139%** at disk thresholds 140, 160, and 180.
This agrees with the response's approximately 0.1% result, far smaller than
the approximately 12% opening aspect difference. The small ellipse difference
combines physical disk shape and scanner scale; it does not isolate either.

See [the averaged openings and overlaid profiles](figures/drive_ensemble.png).
The full results and input fingerprints are retained in
[the verification report](data/response_verification.json).

## Music-hole size limits

The detected music-hole area corresponds to a median circular diameter of
0.10934 inch at threshold 150, falling to 0.10660 inch at threshold 170.
This supports retaining the direct 0.116-inch caliper measurement instead of
substituting the white-region diameter.

For comparison, the original threshold-150 drive mask had median projected
spans of 0.09558 inch radial and 0.08572 inch tangential. The edge comparison
above replaces those white-region spans as the basis for drive-hole size.

## Audio direction results

The recording is decoded to mono 24 kHz for analysis. A short-time Fourier
transform supplies energy near each provisional tine's fundamental and weaker
second and third harmonics. Positive changes in log energy supply onset
evidence. These channels are folded across the revolution period, smoothed
periodically, and normalized separately.

For each scanned music hole, the script compares both signs of the angle-to-time
mapping while searching recording phase. At **28.126 seconds per revolution**:

| Chronological angle direction | Best summed onset score |
| --- | ---: |
| Increasing angle | 67.37 |
| Decreasing angle | 261.74 |

Decreasing-angle order scores about **3.89 times higher**, and wins for every
tested period: 28.08, 28.10, 28.12, 28.126, 28.14, and 28.16 seconds. This
independently supports clockwise chronological holes on the stationary top-face
CAD design and counterclockwise physical rotation viewed from above.

These are descriptive scores, not probabilities or statistical significance.
The analysis uses the provisional pitch map, does not transcribe the whole
song, and does not establish every tine's pitch independently. It tests
direction, not an exact new revolution period. The best recording phase near
21.107 seconds includes the loose disk's scan orientation and recording start;
it is not a mechanical reader angle. The CAD default 230° remains arbitrary.

## Independent pitch-map comparison

The new check searches **22 starting white keys from C2 through C5**, each
followed by consecutive white keys increasing outward. It retains the already
supported decreasing-angle chronology and 28.126-second period. It computes
pitch-specific positive log-energy changes at 24 kHz, folds them into 10 ms
phase bins, and searches recording phase. Two FFT windows (4096 and 8192
samples) and two frequency-evidence choices test sensitivity:

| FFT samples | Frequency evidence | Best start | Score | Next start | Next score |
| --- | --- | --- | ---: | --- | ---: |
| 4096 | Fundamental only | **C4** | 279.0 | A3 | 161.8 |
| 4096 | Fundamental plus weaker harmonics | **C4** | 261.7 | C3 | 199.8 |
| 8192 | Fundamental only | **C4** | 302.2 | A3 | 169.1 |
| 8192 | Fundamental plus weaker harmonics | **C4** | 265.5 | C3 | 196.1 |

C4 also ranks first when the first and second complete recording revolutions
are analyzed separately in all four configurations. A further check fits
each candidate's phase on the first revolution and evaluates the second
revolution **at that fixed training phase**. C4 again has the highest held-out
score in each configuration. Later partial-revolution audio is excluded from
those separate-revolution checks.

This independently supports **C4 through G6 on occupied tracks 1–19** under
the consecutive-white-key assumption. It is not an independent isolated
measurement of every tine. Tracks 18 and 19 have only one reference attack
each; track 20 has none, so **A6 remains inferred by continuation**.
`geometry.json` now records that provenance explicitly without changing pitches.

Octave alternatives receive some harmonic evidence, which is why the
fundamental-only comparison is useful. Scores are descriptive, not probabilities
or calibrated significance. They do not test arbitrary per-track tuning or
non-diatonic maps, and their magnitude depends on analysis settings. The other
AI's different numeric scores need not match these to support the same ranking.

See [the primary candidate comparison](figures/pitch_map_candidates.png) and
[all rankings and separate-revolution checks](data/response_verification.json).

## Reproduce the check

The production exporters still have no third-party runtime dependencies.
The optional analysis script needs NumPy, SciPy, Pillow, Matplotlib, and an
`ffmpeg` executable for the audio check.

```bash
pip install -e '.[analysis]'
MPLCONFIGDIR=/tmp/symphonium-matplotlib PYTHONPATH=src python3 scripts/check_reference.py \
  --scan /mnt/c/Users/rharr/OneDrive/Documents/img20261001_00272891.png \
  --audio '/mnt/c/Users/rharr/Downloads/116 E Main St 15.m4a'
```

Omit `--audio` for a scan-only run. `--disc-threshold`, `--hole-thresholds`,
`--geometry`, and `--output` are adjustable. The first hole threshold supplies
the overlay and audio-hole positions; the remaining thresholds check sensitivity.

Reproduce the independent response checks with:

```bash
MPLCONFIGDIR=/tmp/symphonium-matplotlib PYTHONPATH=src python3 scripts/verify_response.py \
  --scan /mnt/c/Users/rharr/OneDrive/Documents/img20261001_00272891.png \
  --audio '/mnt/c/Users/rharr/Downloads/116 E Main St 15.m4a'
```

This writes averaged-hole profiles, figures, candidate scores, a decoded audio
copy, and a full report under `output/response_check/`. The committed report
records the scan, audio, geometry, script, and supplied CSV fingerprints. Its
geometry and scripts are the historical versions in
[commit 6f6a771](https://github.com/rharriszzz/symphonium-disc-maker/tree/6f6a77180d75839c6a91c49a42ff66a15c8eea5b),
before the center-hole correction above. That correction does not change the
drive-ring or pitch-map results; the historical report has been preserved.
The original supporting files remain unchanged and outside Git.

Generated files in `output/reference_check/` include:

- `scan_overlay.png`: cyan CAD drive openings, purple track centers, green
  detected music-hole centers. Only the regular drive ring's phase is aligned
  to the loose scan; its CAD radius and hole size are unchanged.
- `drive_opposites.png`: opposite drive-hole crops and both local edge profiles,
  identifying measurements across versus along the scanner shadow.
- `audio_direction.png` and `audio_direction.csv`: both direction scores over
  recording phase at the nominal period.
- `report.json`: calibration, threshold checks, source fingerprints, and audio
  scores across trial periods.
- `detected_holes.json` and `detected_holes.csv`: detected positions,
  orientations, optical dimensions, and note-track assignments.
- `reference_audio.wav`: decoded analysis copy; the original M4A is unchanged.

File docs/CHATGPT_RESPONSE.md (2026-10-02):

# ChatGPT response to `docs/QUESTIONS_FOR_CHATGPT.md`

Date: October 1, 2026  
Repository: `rharriszzz/symphonium-disc-maker`

This response addresses the four numbered questions in `docs/QUESTIONS_FOR_CHATGPT.md`.
It incorporates an independent re-check of the original 600 dpi scan and the original
M4A recording. Where conclusions remain uncertain, that is stated explicitly.

---

## Question 1 — Are the drive openings really about 0.100 in radial × 0.090 in tangential?

### Conclusion

**Yes. I independently agree with the rectangular interpretation and with using
0.100 in radial × 0.090 in tangential as the first prototype nominal.**

The older `0.095 in square` value should be treated as a discarded averaging
placeholder, not as the best current interpretation of the original disk.

### Why I agree independently

Codex used grayscale edge gradients on selected opposite/cardinal holes. I used a
different ensemble method on the full-resolution original scan:

1. Detect all 143 drive openings from the 5100 × 6600 scan.
2. For each detected opening, transform a local image patch into coordinates whose:
   - X axis is local **radial**,
   - Y axis is local **tangential**.
3. Average all 143 locally aligned patches.

This is useful because the physical opening shape is rotated into the same local
orientation for every hole, while the scanner's fixed downward shadow rotates through
all possible directions in the local coordinate system. The true radial/tangential
shape reinforces in the average; a fixed scanner-shadow bias tends to wash out rather
than reinforce as one axis.

Using simple brightness crossings on that averaged patch does **not** give the absolute
physical edge location as cleanly as Codex's across-shadow gradient method; it measures
more nearly the bright interior. But it gives a strong independent shape ratio.

At representative thresholds:

| Average-patch threshold | Radial width (px) | Tangential width (px) | Ratio |
| ---: | ---: | ---: | ---: |
| 130 | 54.67 | 49.02 | 1.115 |
| 150 | 53.06 | 47.16 | **1.125** |
| 170 | 51.67 | 45.44 | 1.137 |
| 190 | 50.47 | 43.90 | 1.150 |

Codex's independent across-shadow edge measurements were:

```text
radial      59.625 px
tangential  53.000 px
ratio       1.125
```

The **same ~1.125 aspect ratio at threshold 150** is notable because the two
methods choose different optical boundaries.

### Scanner X/Y scaling cannot explain the difference

I also fit an ellipse to the outer disk boundary using several segmentation settings.
The fitted scan axes differ by only about **0.08–0.11%**:

```text
typical fitted major/minor axis ratio ≈ 1.001
```

The drive-opening dimensional difference is around **12%**.

Therefore scanner X/Y scale anisotropy is two orders of magnitude too small to explain
the radial/tangential difference.

### The user's physical measurements also support the rectangular result

The user had reported drive-hole side measurements of approximately:

```text
0.09 in
and, on an earlier measurement, about 0.10 in
```

Those two readings are naturally consistent with measuring different axes of a
slightly rectangular opening.

There is also a particularly useful independent radial check:

```text
disk radius             = 3.500 in
drive center radius     = 3.373 in
radial opening nominal  = 0.100 in
predicted outer gap     = 3.500 - 3.373 - 0.050
                        = 0.077 in
```

The user's direct physical measurement was approximately:

```text
disk edge to outer edge of drive opening = 0.0760 in
```

That agrees very well with a **0.100-inch radial** opening.

For comparison:

```text
0.090 radial opening -> predicted gap 0.082 in
0.095 radial opening -> predicted gap 0.0795 in
```

So the direct edge-clearance measurement independently favors a radial dimension close
to 0.100 in.

### Could scanner shadow still explain all ~6.6 pixels?

I do not think so.

A shadow obviously changes the apparent optical boundary and therefore can move an
individual edge by one or several pixels. It is reasonable to retain the practical
1–2 pixel boundary allowance already documented by Codex.

But four things argue against the entire ~6.625-pixel axis difference being a shadow
artifact:

1. opposite cardinal groups agree within about 0.4 pixel in Codex's analysis;
2. the fixed scanner shadow reverses its local-axis relationship on opposite sides;
3. the 143-hole local-coordinate ensemble average preserves essentially the same
   aspect ratio even though the fixed global shadow direction is averaged around
   the ring;
4. the physical caliper and edge-clearance measurements support ~0.100 in radially.

### Recommended current prototype geometry

Keep:

```text
drive opening radial dimension      = 0.100 in
drive opening tangential dimension  = 0.090 in
```

with the explicit status:

```text
scan-informed prototype nominal; mechanical fit to be validated on the first part
```

The scan edge results (~0.0991 × ~0.0881 in) are useful measurements, but rounding to
0.100 × 0.090 in for the first prototype is sensible and consistent with the physical
measurements.

### Independent artifact produced during this response

I produced an aligned 143-hole average and profile data during the check. The raw CSV is
included with the response package as:

```text
aligned_drive_profiles.csv
```

The absolute profile threshold widths should **not** replace Codex's better
across-shadow absolute edge estimates; their useful independent result is the
radial/tangential aspect ratio.

---

## Question 2 — Which mechanism photographs show the center post, retaining geometry, and seating region?

### Original photographs retained

Yes. I still have the original mechanism photographs from the conversation.

The most useful files are included with this response package:

```text
IMG_3359.jpeg
IMG_3360.jpeg
IMG_3361.jpeg
IMG_3362.jpeg
```

### What each image shows

#### `IMG_3359.jpeg`

Shows the *Unchained Melody* disk **installed**, printed/top face upward.

Useful for:

- confirming which face is uppermost in normal use;
- seeing the disk centered in the mechanism;
- seeing the drive gear at the rim;
- general relationship of disk and plucker assembly.

It does not expose the hidden center seating neck.

#### `IMG_3360.jpeg`

Another installed-disk view from a different angle.

Useful for the overall mechanism/disk relationship but not a clean dimensional view of
the hidden center-post seating region.

#### `IMG_3361.jpeg`

This is the **best center-post photograph** because the disk is removed.

It clearly shows:

- the black center post/retaining feature;
- the full row of plucker channels/tines;
- the surrounding support structure.

The visible top of the center post is not shaped like a long, simple precision
cylindrical shaft. It appears rounded/tapered/retainer-like.

However, the image does **not** cleanly expose or dimension a distinct smaller
cylindrical seating neck underneath the retaining feature. The black part is small,
viewed obliquely, and some of the relevant lower profile is visually merged with the
surrounding black mechanism.

Therefore the photo supports a **retainer/taper interpretation**, but it does not prove
the exact diameter on which the disk finally seats.

#### `IMG_3362.jpeg`

Close-up with the disk installed near the drive gear.

This is particularly useful for confirming that the **drive tooth is smaller than the
drive opening**, i.e. intentional clearance.

It is not the best image for the center-post seating neck.

### Was the seating-neck diameter ever measured?

**No.**

The measured value supplied by the user was:

```text
visible center-post feature diameter = 0.2085 in
```

The original disk center hole was measured as:

```text
center-hole diameter = 0.1960 in
```

No separate measurement was made of:

- a lower neck diameter;
- a disk seating diameter;
- a taper minimum;
- the post diameter exactly at the disk contact plane.

So the current correct statement remains:

> The known-working original disk has a 0.196-inch center hole.  
> A visible post feature measures 0.2085 inch.  
> The photo is consistent with a rounded/tapered retaining feature rather than a uniform
> 0.2085-inch shaft, but the actual seating-neck diameter was not measured.

### Manufacturing implication

Keep the first prototype center hole at:

```text
0.196 in
```

because this directly duplicates the known-working original.

Do not enlarge it to 0.2085 in merely to match the widest measured post feature.

A small center-hole/material coupon remains a good optional fit test if the supplier
can include one cheaply.

---

## Question 3 — How well was the C4–A6 pitch map actually established?

### Short answer

The map was **not independently measured as 20 isolated tine recordings**.

However, after a new independent global scan/audio test, the map is better supported
than a mere sampler assumption.

The strongest statement now justified is:

> **Tracks 1–19 on the scanned Unchained Melody disk are strongly supported as the
> consecutive white-key sequence C4 through G6, inner to outer. Track 20 (A6) is
> inferred by continuation and is not directly played on this reference disk.**

### What was known before this re-check

Several clues had pointed to the 20-note white-key mapping:

1. the mechanism has 20 tine/plucker positions;
2. pitch increases with radius;
3. an existing independent Mr. Christmas disk-generator project used a 20-note
   consecutive diatonic/white-key scale;
4. spectral peaks in the recording were consistent with such a scale;
5. the scan/audio direction comparison worked well with the provisional map.

But that did not independently prove every pitch.

### New independent global pitch-map check

I re-ran the scan/audio comparison while allowing the **starting white key and octave**
to vary.

Assumptions retained for this test:

- the 19 occupied tracks form consecutive white keys;
- pitch rises outward;
- chronological direction is the already supported decreasing-angle direction.

The start pitch was varied across plausible white keys, and for each candidate map I
searched recording phase and summed pitch-specific onset evidence at all 145 scanned
music holes.

Top candidates included:

| Occupied-track map | Best onset score |
| --- | ---: |
| **C4 → G6** | **198.7** |
| F2 → C5 | 148.0 |
| C3 → G5 | 137.5 |
| B2 → F5 | 103.2 |
| G2 → D5 | 70.5 |
| E4 → B6 | 69.6 |
| A3 → E6 | 66.6 |
| D4 → A6 | 65.9 |

These are **descriptive correlation/onset scores, not probabilities**.

The C4→G6 occupied-track sequence is the strongest candidate in this test and uses a
phase around 21.08 s, essentially the same region found by the earlier direction
analysis.

This materially strengthens the octave/start-note assignment.

### Which tracks have repeated evidence?

The 145 holes occupy the first 19 radial rows with the following counts:

```text
track  1:  5 holes
track  2:  3
track  3:  5
track  4:  4
track  5:  9
track  6:  7
track  7:  6
track  8: 18
track  9:  9
track 10: 15
track 11:  6
track 12: 11
track 13:  9
track 14:  4
track 15: 12
track 16: 11
track 17:  9
track 18:  1
track 19:  1
track 20:  0
```

Therefore:

- tracks **1–17** have multiple physical attacks in the reference disk and contribute
  repeated evidence;
- tracks **18–19** occur only once each, so their individual assignments are much less
  strongly tested by this song;
- track **20 is absent** from the reference disk, so **A6 is inferred**, not measured
  from *Unchained Melody*.

### Current pitch-status table

| Track | Working pitch | Status |
| ---: | --- | --- |
| 1 | C4 | Supported by global scan/audio map; multiple attacks |
| 2 | D4 | Supported by global scan/audio map; multiple attacks |
| 3 | E4 | Supported by global scan/audio map; multiple attacks |
| 4 | F4 | Supported by global scan/audio map; multiple attacks |
| 5 | G4 | Supported by global scan/audio map; multiple attacks |
| 6 | A4 | Supported by global scan/audio map; multiple attacks |
| 7 | B4 | Supported by global scan/audio map; multiple attacks |
| 8 | C5 | Supported by global scan/audio map; multiple attacks |
| 9 | D5 | Supported by global scan/audio map; multiple attacks |
| 10 | E5 | Supported by global scan/audio map; multiple attacks |
| 11 | F5 | Supported by global scan/audio map; multiple attacks |
| 12 | G5 | Supported by global scan/audio map; multiple attacks |
| 13 | A5 | Supported by global scan/audio map; multiple attacks |
| 14 | B5 | Supported by global scan/audio map; multiple attacks |
| 15 | C6 | Supported by global scan/audio map; multiple attacks |
| 16 | D6 | Supported by global scan/audio map; multiple attacks |
| 17 | E6 | Supported by global scan/audio map; multiple attacks |
| 18 | F6 | Globally supported, but only one physical reference attack |
| 19 | G6 | Globally supported, but only one physical reference attack |
| 20 | A6 | **Inferred by continuation; not present on reference disk** |

### Important limitation

I attempted simple event-local spectral extraction for each individual track. It was
not clean enough to call every track independently measured, because the tines ring for
a long time and adjacent musical events overlap strongly.

That is exactly why the sparse Pachelbel sampler disk remains valuable: it can give us
one clean attack per tine with long separation.

### Existing / unavailable artifacts

#### Available

- Original 600 dpi scan:
  `img20261001_00272891.png`
- Original recording:
  `116 E Main St 15.m4a`
- Codex's reproducible current analysis:
  `scripts/check_reference.py`
- Codex-generated detected-hole tables under local
  `output/reference_check/`

#### Not available as a formal retained artifact from my earlier scratch work

- No isolated-tine recording set exists.
- No reliable full MIDI transcription of *Unchained Melody* was produced.
- My earlier exploratory scan/audio scripts were scratch analyses rather than a
  preserved project file.

Codex's checked-in `scripts/check_reference.py` is now the correct reproducible analysis
foundation.

### Recommendation

Keep the current C4–A6 map in `geometry.json`, but document track 20 as inferred until
the Pachelbel sampler is physically played and recorded.

---

## Question 4 — BossKut Gazelle / CUTOK / Windows 11 status

### What I have

I do **not** have a surviving original BossKut installer, Funtime installer, or CUTOK
driver package from the user's old installation.

I also do not have a verified copy of the CUTOK driver binary that I would recommend
installing blindly.

### What is officially verified today

Craft Edge currently states all of the following:

1. **Sure Cuts A Lot 6 supports the BossKut Gazelle.**
2. SCAL 6's published Windows requirements include **Windows 11**.
3. Craft Edge has a current **BossKut Gazelle Cutter Setup** page.
4. That setup page says that on Windows, the user must first install the **CUTOK
   Driver**; on Mac, no driver is needed.
5. The setup page says that after driver installation the cutter should appear as a
   CUTOK printer, after which SCAL can use USB / `<Auto>`.

Official current sources checked October 1, 2026:

```text
https://craftedge.com/help/surecutsalot6/index.php
https://surecutsalot.com/support/faq/faq_surecutsalot.php
https://www.craftedge.com/tutorials/gazelle/setup.php
https://craftedge.com/download/downloads.php
```

This verifies:

```text
SCAL 6 itself: Windows 11 supported
SCAL 6 cutter list: BossKut Gazelle supported
Gazelle Windows setup: requires CUTOK driver
```

### What is NOT verified

The Craft Edge Gazelle setup page links the CUTOK driver to:

```text
https://www.cutok.com/Support.htm
```

That target is currently not reliably retrievable in my web check.

Also, Craft Edge's current "Extra Downloads" page does **not** visibly list a CUTOK
driver package.

Therefore:

> **I cannot currently verify an official, downloadable CUTOK driver package from
> Craft Edge/CUTOK that has been demonstrated end-to-end on Windows 11 with this
> particular Gazelle.**

That distinction matters.

SCAL's Windows 11 compatibility plus its Gazelle support does **not**, by itself, prove
that the legacy CUTOK printer driver will install and operate correctly on this
specific Windows 11 system.

### Third-party evidence

I found a current third-party Brazilian support/download page for the CUTOK DC330 that
explicitly answered a 2024 customer question saying the driver works on Windows 11:

```text
https://sulink.com.br/produto/plotter-de-recorte-dc330-drivers-para-instalacao/10008001
```

This is **not an official Craft Edge or CUTOK source** and I have not downloaded,
inspected, checksum-verified, or installed that package.

It should therefore be treated only as a useful lead, not as a recommended driver
source yet.

Other driver-index sites claim Windows 11 support as well, but those are even less
desirable as a first source for executable/driver software.

### Historical evidence

Older instructions identify the Gazelle USB device as the CUTOK DC330 printer driver.
For example, older Gazelle/Funtime documentation explicitly tells the user to select:

```text
CUTOK DC330
```

for the Gazelle USB connection.

This makes the CUTOK DC330 driver relationship plausible and historically well
supported, but does not prove current Windows 11 driver installation.

### Mac status

Craft Edge's Gazelle setup says:

```text
Mac: no CUTOK driver needed
```

and SCAL 6 is available for macOS.

However, I have not demonstrated an actual current Mac-to-Gazelle connection in this
project. Treat Mac as a fallback path, not as verified hardware success.

### Recommended Windows-11-first procedure

The safest sequence is:

1. Install the current **SCAL 6 trial** from Craft Edge.
2. Do **not** install a random driver utility.
3. Inspect the Gazelle's USB hardware ID in Windows Device Manager after connecting it.
4. Determine whether Windows already has/accepts a CUTOK DC330 driver.
5. If a separate legacy driver is needed, prefer:
   - a file obtained directly from Craft Edge support, or
   - a verifiable original CUTOK package,
   before using a third-party mirror.
6. If the official linked driver remains unavailable, contact Craft Edge support and
   ask specifically for the current BossKut Gazelle / CUTOK DC330 Windows 11 driver
   package.
7. Only after the cutter appears correctly in Devices and Printers / Device Manager
   should SCAL be tested for actual cutting and then Print & Cut registration.

### Bottom line on Gazelle

Current verified statement:

> **SCAL 6 officially supports both Windows 11 and the BossKut Gazelle, and Craft Edge's
> Gazelle instructions require a CUTOK driver on Windows. However, the current official
> CUTOK driver download itself has not been retrieved or end-to-end verified on Windows
> 11 in this project.**

That is more precise than my earlier suggestion that the Gazelle was simply "Windows
11 supported."

---

# Recommended updates to the repo after this response

1. Accept the current prototype drive opening:
   ```text
   0.100 in radial × 0.090 in tangential
   ```
   and retain its prototype/uncertainty status.

2. Add the independent scan facts to `REFERENCE_CHECK.md`:
   - scan outer-boundary anisotropy only ~0.1%;
   - 143-hole aligned-patch aspect ratio independently agrees with ~1.125.

3. Update pitch-map provenance:
   - tracks 1–19: global scan/audio evidence favors C4→G6;
   - tracks 18–19: only one physical hole each on this song;
   - track 20 A6: inferred, not directly measured.

4. Add the four original photos to a local reference-material workflow if desired,
   especially `IMG_3361.jpeg`.

5. Keep the first manufactured disk center hole at **0.196 in**.

6. For the Gazelle, change documentation from any unconditional Windows-11 claim to:
   ```text
   SCAL 6 supports Windows 11 + Gazelle;
   legacy CUTOK driver availability/installation remains to be verified.
   ```

---

# Supporting artifacts supplied with this response package

```text
CHATGPT_RESPONSE.md
IMG_3359.jpeg
IMG_3360.jpeg
IMG_3361.jpeg
IMG_3362.jpeg
aligned_drive_profiles.csv
```

The original 25 MB scan and original M4A are **not duplicated in this package** because
Codex already has them locally at the paths recorded in `REFERENCE_CHECK.md`.

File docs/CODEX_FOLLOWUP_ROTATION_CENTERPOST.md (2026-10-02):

# Symphonium Disc Maker — Follow-up on Rotation Direction, Scan Face, Time Zero, and Center Post

**Date:** 2026-10-01\
**Repository:** `rharriszzz/symphonium-disc-maker`\
**Reference disc:** *Unchained Melody*\
**Machine:** Mr. Christmas Animated Holiday Symphonium 140-24021

This document answers two follow-up questions from the Codex CLI agent and supersedes the more conservative wording in the earlier handoff where noted.

---

# 1. What face was scanned?

## Confirmed

The 600 dpi scan is of the **top / printed face** of the original disc.

The machine, however, **reads/plucks the disc from underneath**.

Therefore:

- the scan coordinate system is a **top-view coordinate system**;
- the plucker/follower mechanism contacts the opposite face;
- looking at the same physical disc from underneath produces a mirror image of the angular ordering seen in the scan.

The radial positions do not change when switching faces, but clockwise/counterclockwise descriptions do.

For clarity, all conclusions below first use the **top-face / scan view**.

---

# 2. Can the playback rotation direction be determined?

## Yes — with high confidence

The 600 dpi scan and the audio recording are sufficient to determine the direction.

The earlier handoff said the direction was "not established." That was too conservative.

## Coordinate convention

For the full-resolution scan:

- disc center is the origin;
- 0 degrees points to the right;
- positive angle is **counterclockwise when viewed from the scanned/top face**.

This is the ordinary mathematical polar-angle convention after reversing the image Y axis.

The scan contains:

- 145 music-note holes;
- 19 occupied radial note tracks;
- lower-pitch tracks closer to the center;
- higher-pitch tracks farther outward.

The mechanism itself has 20 tracks/tines; *Unchained Melody* appears not to use the outermost one.

## Audio method

The original M4A was analyzed directly.

A complete, reliable MIDI transcription of *Unchained Melody* was **not** required and should not be claimed.

Instead, the direction test used the much stronger prior information already available:

1. The radial track of every scanned hole is known.
2. The inner-to-outer pitch order is known/provisionally mapped:
   `C4, D4, E4, ... G6` for the 19 occupied rows.
3. The recording contains a little more than two revolutions.
4. The revolution time is about 28.1 seconds.
5. For each of the 19 possible recorded pitches, a pitch-specific onset-strength channel was calculated from the recording.
6. The 145 scanned holes were mapped into those 19 channels.
7. The angular sequence was tested in both possible directions while allowing an arbitrary phase offset.

The audio analysis used each target pitch's fundamental plus weaker harmonic contributions, then looked for increases in energy associated with attacks.

The audio was folded by the revolution period so both recorded revolutions contributed to the comparison.

---

# 3. Numerical direction result

For a working revolution period near 28.126 s, the two angular hypotheses gave approximately:

| Top-face angular relationship | Best correlation score | Peak significance |
|---|---:|---:|
| time increases as angle **increases** | ~63 | ~3.7 sigma |
| time increases as angle **decreases** | **~319** | **~9.6 sigma** |

The result remains essentially unchanged when the assumed revolution period is varied over a useful range:

| Trial period | Increasing-angle score | Decreasing-angle score |
|---:|---:|---:|
| 28.08 s | 62.0 | **321.0** |
| 28.10 s | 65.7 | **321.1** |
| 28.12 s | 65.9 | **320.4** |
| 28.126 s | 63.0 | **318.8** |
| 28.14 s | 62.0 | **319.6** |
| 28.16 s | 55.3 | **316.2** |

So the preferred sequence direction is not a marginal result.

It is roughly five times stronger in raw score and substantially more statistically distinct.

---

# 4. What does that imply about physical rotation?

Let:

- `alpha` = a hole's angular coordinate on the stationary disc, viewed from the top;
- `beta` = fixed reader/plucker angular location;
- `omega` = physical angular velocity, positive for counterclockwise rotation viewed from the top.

A hole plays when:

```text
alpha + omega*t = beta   (mod 2*pi)
```

Therefore:

```text
t = (beta - alpha) / omega
```

The scan/audio result shows:

```text
play time decreases as top-face alpha increases
```

or equivalently:

```text
t ∝ -alpha
```

That requires:

```text
omega > 0
```

under the coordinate convention above.

## Conclusion

> **The disc rotates counterclockwise when viewed from the top / printed / scanned face.**

Because the machine reads the underside:

> **The same physical rotation appears clockwise when viewed from underneath, looking directly at the plucker side.**

These are the same physical motion described from opposite sides.

---

# 5. What direction should chronological note events be laid out on the top face?

This distinction is important.

The disc physically rotates **counterclockwise viewed from above**.

For a fixed underside reader, later-playing holes must initially lie progressively in the opposite angular direction.

Therefore, on a stationary design viewed from the **top face**:

> **Chronological playback order proceeds clockwise around the disc.**

Using standard mathematical top-face angles:

```text
angle(t) = start_angle - 360° * t / revolution_time
```

not:

```text
angle(t) = start_angle + 360° * t / revolution_time
```

## Consequence for the current repo

The current code uses an increasing angle for later events.

For example, `svg.py` currently has the equivalent of:

```python
angle_deg = start_angle_degrees + 360.0 * frac
```

and `dxf.py` similarly adds the event phase.

Given the now-established top-face playback direction, this should be reviewed and very likely changed to:

```python
angle_deg = start_angle_degrees - 360.0 * frac
```

with equivalent handling in DXF.

The repo should explicitly document which face its geometric output represents.

Recommended convention:

> **All SVG/DXF arrangement geometry is defined as viewed from the disc's printed/top face.**

Then chronological events use decreasing polar angle.

---

# 6. What does the underside-reading fact change?

The note holes and drive holes are through-cuts, but the musical pattern is not rotationally mirror-symmetric.

If the top-face design is viewed from underneath, its angular ordering is mirrored.

Thus:

- top face: physical rotation = counterclockwise;
- underside view: physical rotation appears clockwise;
- chronological hole sequence on the stationary top-face artwork = clockwise;
- chronological hole sequence as seen from underneath = counterclockwise.

This needs to be kept straight when comparing:

- the top-face scan,
- photographs of the installed disc,
- underside mechanism geometry,
- CAD files,
- labels.

For manufacturing, the DXF itself is only 2-D through-cut geometry and does not inherently have a "top" unless we assign one.

For this project, assign the CAD view to the **printed/top face** and keep that convention everywhere.

---

# 7. What is the meaning of the current `230°` time-zero angle?

## Confirmed: it has no established mechanical significance

The value:

```text
start_angle_degrees = 230.0
```

was chosen for visual/layout convenience when generating an early disc preview.

It was **not** measured from:

- the plucker assembly;
- a particular drive tooth;
- an index mark;
- the label;
- a keyed mounting feature;
- the scanner;
- the start of the M4A recording.

Therefore:

> **230° is an arbitrary rotational phase.**

It may remain a user-selectable layout phase, but it must not be documented as a measured mechanism angle.

---

# 8. Can the scan/audio correlation determine the physical reader angle?

Not from the current data alone.

The best audio correlation has a phase offset around 21.1 s within the revolution.

However, that offset contains at least two unknown phases:

1. the arbitrary rotational orientation in which the loose disc was placed on the scanner;
2. the arbitrary rotational phase of the disc at the instant the audio recording began.

Therefore that correlation phase cannot be converted directly into a physical "reader is at N degrees" statement.

The **sign/direction** is robust because those arbitrary rotations only add a constant phase.

The **absolute angular zero** is not.

---

# 9. Summary of rotation conclusions

## Confirmed / high confidence

- The scan is the **top / printed face**.
- The machine reads/plucks the disc from **underneath**.
- The disc rotates **counterclockwise viewed from the top**.
- The same rotation appears **clockwise viewed from underneath**.
- On stationary top-face CAD artwork, chronological note events proceed **clockwise**, i.e. toward decreasing mathematical angle.
- The repo's current positive-time/positive-angle arrangement convention should be corrected or explicitly redefined.
- `230°` is arbitrary, not a measured mechanical time-zero angle.

## Not established

- A physically meaningful absolute reader angle in scan coordinates.
- A unique mechanical time-zero location.

---

# 10. Center hole versus center post

The two direct measurements are:

```text
original disc center-hole diameter = 0.1960 in
measured center-post feature       = 0.2085 in
```

Difference:

```text
0.2085 - 0.1960 = 0.0125 in
```

That is:

```text
0.00625 in interference per side
```

and the measured post feature is about 6.4% larger in diameter than the hole.

If those were a rigid uniform shaft and rigid hole at the same seating diameter, they would not be a normal sliding clearance fit.

---

# 11. Can the center-post discrepancy be resolved from the existing information?

## Partly, but not completely

The photographs of the bare mechanism show that the visible central black post is **not obviously a long uniform precision cylinder**.

It appears rounded / tapered / retaining-post-like.

That supports the interpretation that the 0.2085-inch caliper reading may be the maximum diameter of a retaining portion rather than the diameter on which the disc finally seats.

The original disc is also:

```text
~0.020 in thick
```

and flexible plastic.

A plausible mechanical arrangement is therefore:

1. the 0.196-inch hole passes over a slightly larger rounded/tapered retaining feature;
2. the thin disc flexes temporarily during installation;
3. the disc then rests around or below a smaller neck/seating diameter.

This is mechanically plausible and consistent with the visible shape.

## But this is not fully proven

The photographs do not clearly expose the entire post profile at sufficient resolution to measure:

- the minimum neck diameter;
- the seating diameter directly under the cap;
- the taper;
- the exact height at which the original disc rests.

Therefore do **not** claim that a particular hidden shaft diameter has been measured.

---

# 12. Best-supported interpretation of the 0.196 / 0.2085 discrepancy

The strongest statement justified by the evidence is:

> The original working disc really has a ~0.196-inch center hole.\
> The visible post has a measured feature of ~0.2085 inch.\
> The post appears to have retaining/tapered geometry rather than being a simple uniform shaft.\
> The original thin flexible disc therefore most likely passes over a larger retaining portion and seats on a smaller region, or flexes over the retainer during installation.

This is more plausible than treating 0.2085 inch as the required manufacturing hole diameter.

---

# 13. Manufacturing consequence: keep the center hole at 0.196 inch for now

The original disc is the known-working reference.

Therefore the first manufactured disc should duplicate:

```text
center hole = 0.196 in
```

unless a direct new measurement proves otherwise.

Do **not** enlarge it to 0.2085 inch merely because the visible post feature measures 0.2085 inch.

A 0.2085-inch hole could remove whatever retention the original design intentionally has.

---

# 14. Material consequence of the center-post fit

This discrepancy makes material flexibility more important than previously appreciated.

If the original 0.196-inch hole must flex over a ~0.2085-inch retaining feature, then a replacement material must tolerate that snap-over action.

This affects the comparison between candidate materials:

### 0.020-inch PETG

Advantages:

- matches original thickness exactly;
- readily available from Xometry in the required nominal thickness.

Possible concern:

- PETG may be stiffer and less forgiving in a snap-over center-post fit than the original unknown plastic.

### 0.030-inch polypropylene

Advantages:

- polypropylene is very flexible and fatigue-resistant;
- likely comfortable with a snap-over retaining post.

Possible concern:

- 0.030 inch is 50% thicker than the measured 0.020-inch original.

Therefore center-post fit is another reason that material choice should be physically tested rather than decided from thickness alone.

---

# 15. Very useful low-cost center-hole test

Before paying for multiple complete discs, a small material test coupon could include several center holes:

```text
0.190
0.194
0.196
0.198
0.202
0.206
0.210 in
```

in the candidate material.

Try them manually over the post.

This would establish:

- whether the post is acting as a snap retainer;
- how much material flex is needed;
- whether PETG is acceptable;
- what manufacturing kerf/tolerance does to the effective hole size.

This test is especially useful if the vendor can add the coupon to the same sheet/order inexpensively.

---

# 16. Additional important repo issue: drive-hole orientation

Independent of the note-direction issue, a separate scan analysis showed that the 143 square drive holes are approximately oriented with their sides **radial/tangential** around the ring.

They are not all globally axis-aligned.

So Codex should fix both:

1. **music-event angular sign**
2. **individual drive-square rotation**

They are separate issues.

---

# 17. Recommended coordinate convention for the repo

To eliminate ambiguity, define this explicitly in code/docs:

```text
View:
    printed/top face of disc

Origin:
    disc center

0 degrees:
    +X / right

Positive angle:
    counterclockwise

Physical playback rotation:
    counterclockwise

Chronological event placement:
    decreasing angle

Event formula:
    theta_event = theta_zero - 360 * time / revolution_seconds
```

The underside mechanism view is then the mirror of this convention.

This convention matches:

- the scanned face;
- ordinary mathematical polar coordinates;
- CAD reasoning;
- the measured playback direction.

---

# 18. Suggested Codex changes

## Geometry / convention

Add something like this to `geometry.json`:

```json
"orientation": {
  "cad_view": "top_printed_face",
  "physical_rotation_top_view": "counterclockwise",
  "chronological_event_direction_top_view": "clockwise",
  "angle_zero_axis": "+x",
  "positive_angle": "counterclockwise",
  "start_angle_degrees": 230.0,
  "start_angle_status": "arbitrary layout phase, not mechanically measured"
}
```

## Arrangement code

Change event angular placement from increasing to decreasing angle, assuming the repo adopts the top-face convention:

```python
angle_deg = start_angle_degrees - 360.0 * frac
```

## Drive holes

Rotate each square with its local polar angle so its sides are radial/tangential.
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

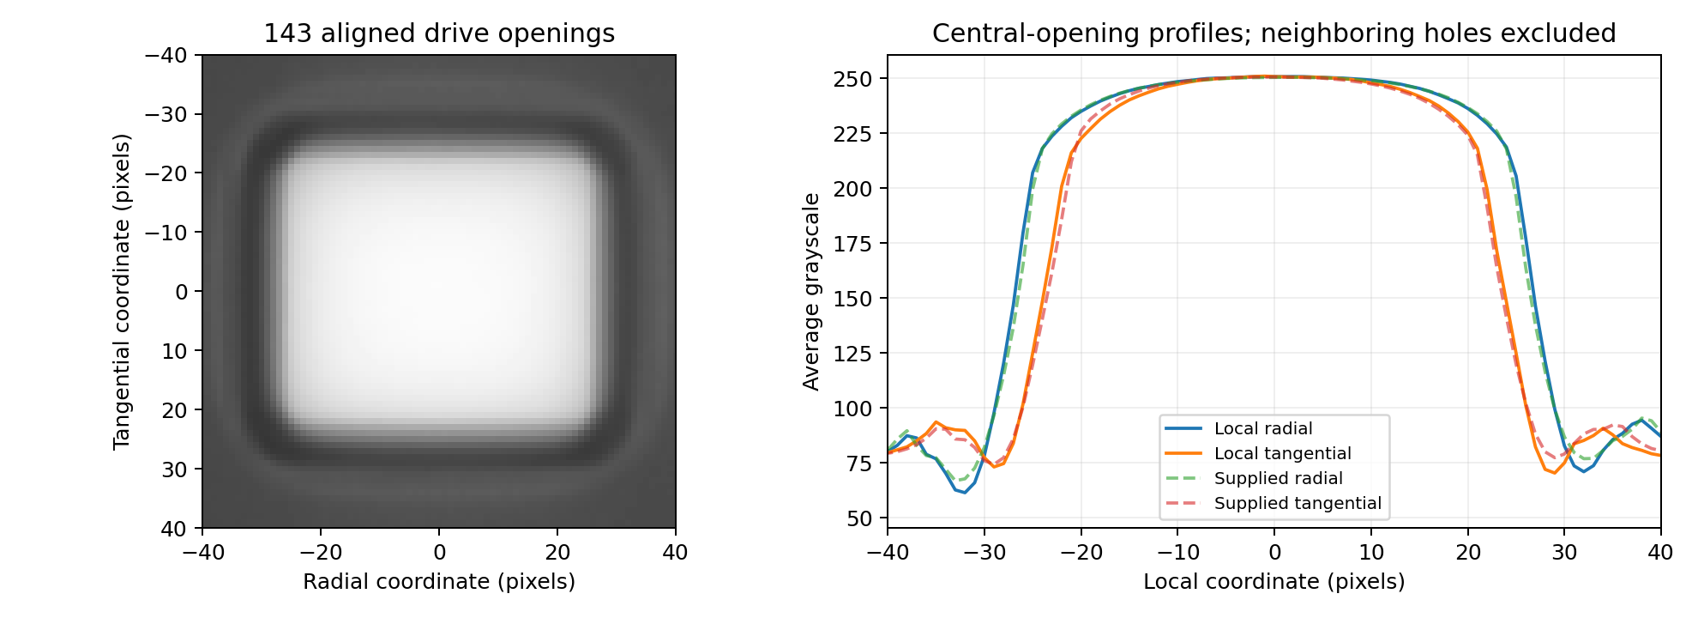
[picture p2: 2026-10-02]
docs/figures/drive_ensemble.png

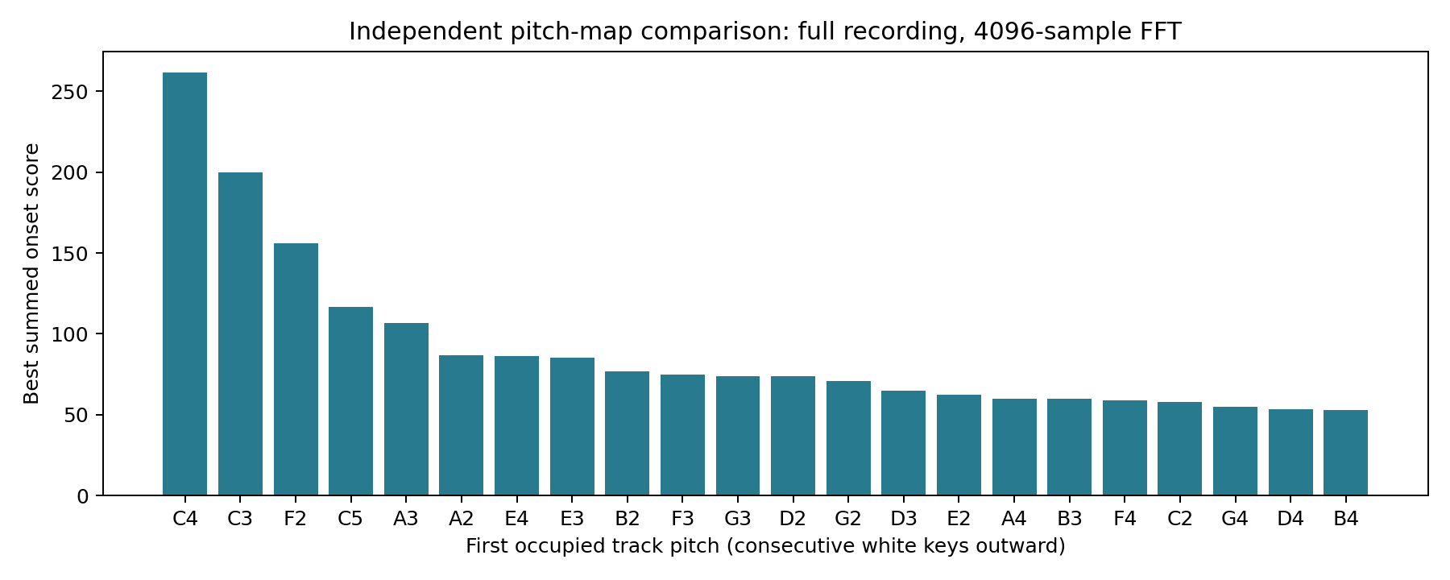
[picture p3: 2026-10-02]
docs/figures/pitch_map_candidates.png

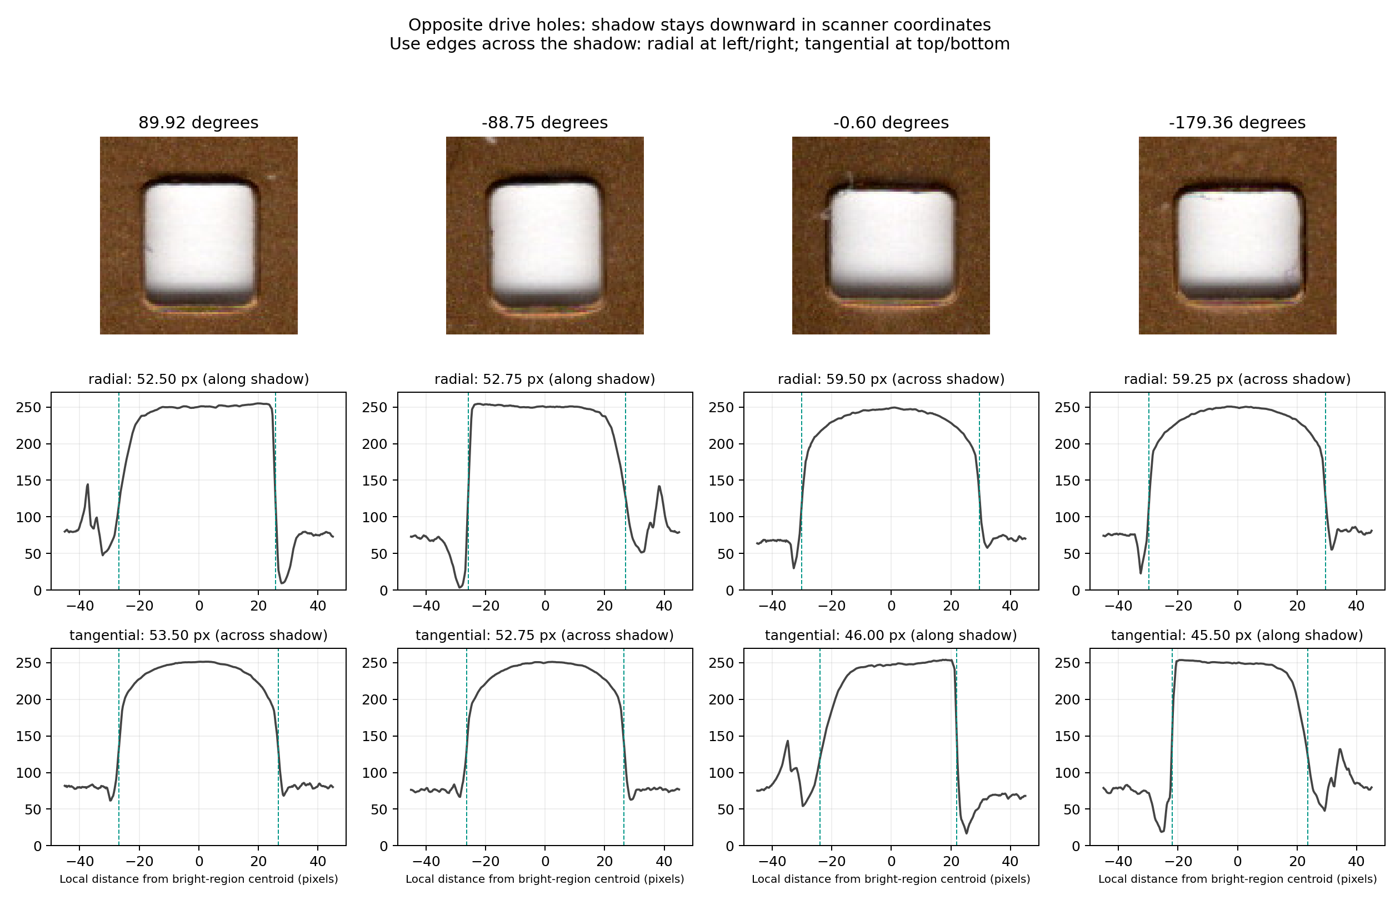
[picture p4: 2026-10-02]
docs/figures/drive_opposites.png

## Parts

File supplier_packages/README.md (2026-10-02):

# Supplier quote packages

Prepared for feasibility review and pricing. Neither package has been submitted.

- [Xometry package](xometry_quote.zip): clear PETG, 0.020 inch (0.508 mm).
- [SendCutSend package](sendcutsend_quote.zip): clear polypropylene, 0.030 inch (0.762 mm).
- [Dimensioned reference drawing](reference_drawing.pdf): one-page overview for both suppliers.
- [Cut-file audit](cut_file_audit.json): closed contours, units, sizes and duplicate checks.

Each ZIP contains the same cutting DXF and reference drawing, its supplier's
quote request, a README and content hashes. Extract it and upload the DXF alone
as manufacturing CAD; provide the PDF and request as supporting material.
The drawing is illustrative, not an actual-size printing or cutting template.

The proposed quantity is one disk from each company, with an optional price
for two. Confirm the material/process, finished-hole fit, drive-opening sizes,
corner rounding, thickness, shipping and total price before paying.
SendCutSend's proposed stock is thicker than the 0.020-inch original; mechanism
clearance remains a physical test. Labels are separate from the cutting files.

The 5.0800 mm center-hole nominal has only
0.1905 mm diametral clearance over the trusted
4.8895 mm post. Each request asks for the minimum clear opening
through the full thickness. General published cutting tolerances are not
a guarantee that this hole will fit. Supplier dimensional changes need review.

See [ordering instructions and supplier links](../docs/ORDERING.md) and the
[complete prototype pack](../prototype_pack/README.md). The latter includes
label files and the sampler recording sequence for the delivered disks.

Regenerate after updating the prototype pack:

```bash
PYTHONPATH=src python3 scripts/build_supplier_packages.py
```

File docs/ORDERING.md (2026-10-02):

# Prototype orders from SendCutSend and Xometry

Prepare a small test order from each company using the same Pachelbel
20-tine sampler. The current files are suitable for asking about feasibility
and pricing; supplier material, process, and tolerances still need confirmation.
No quote has been submitted and no order has been placed.

## Packages ready for supplier review

- [Xometry quote ZIP](../supplier_packages/xometry_quote.zip): request one
  clear PETG disk at 0.020 inch, with an optional price for two.
- [SendCutSend quote ZIP](../supplier_packages/sendcutsend_quote.zip): request
  one clear polypropylene disk at 0.030 inch as the thickness experiment,
  with an optional price for two.
- [Dimensioned reference drawing](../supplier_packages/reference_drawing.pdf):
  geometry and critical dimensions for reviewing both requests.

Each ZIP contains the same `pachelbel_cut_mm.dxf`, a reference PDF, the specific
supplier's `quote_request.txt`, a short README and file hashes. Extract the ZIP
before using a portal that expects individual files. Upload **only the DXF as
manufacturing CAD**, at 1:1 scale in millimeters. Provide the PDF and request
as supporting material for feasibility review. The PDF is illustrative and
must not be measured or used as cutting artwork.

The independent [exported-file audit](../supplier_packages/cut_file_audit.json)
finds 143 separate closed four-edge drive contours and 22 circle contours:
one perimeter, one center opening and 20 music holes. All 165 contours are on
the CUT layer, with no duplicate entities or open drive endpoints. The outer
diameter is 177.800 mm and the center opening is 5.0800 mm. Existing tests
separately check the rotated drive dimensions and nominal clearances.

The next supplier action is **feasibility confirmation and pricing**: use
[SendCutSend contact](https://sendcutsend.com/contact/) for the PP request and
Xometry's [sheet cutting quote entry](https://www.xometry.com/capabilities/sheet-cutting/)
for PETG, requesting manual review if that gauge is unavailable in the portal.
Ask both to state the minimum finished center-hole opening through the full
thickness, so taper or a melted lip cannot prevent clearance over the
4.8895 mm post. Also confirm drive-opening dimensions, location tolerances,
corner rounding, stock thickness, flatness/edge condition and delivered price.
No package has been uploaded or sent; no order has been placed.

Regenerate these delivery packages after updating the prototype pack:

```bash
PYTHONPATH=src python3 scripts/build_supplier_packages.py
```

The [prepared prototype pack](../prototype_pack/README.md) now contains the
[cutting DXF](../prototype_pack/pachelbel_cut_mm.dxf), an annotated preview,
supplier-specific inquiry drafts, label PDFs/SVGs, and a recording sequence.
Its manifest records source and artifact hashes. The nominal preflight finds
positive clearances throughout, including 0.07486 inch from music holes to
drive openings and 0.22038 inch between the closest music holes. It does not
establish supplier process feasibility or mechanical fit.

Regenerate the pack after changing inputs or exporter code:

```bash
pip install -e '.[print]'
PYTHONPATH=src python3 scripts/build_prototype_pack.py --output prototype_pack
```

Supplier information below was checked on October 1, 2026. The repository
contains [the conversation handoff](CODEX_HANDOFF.md), measurement notes, and
[an independent scan/audio check](REFERENCE_CHECK.md). The original scan and
recording are accessible at external Windows paths; neither is stored in Git.

## Proposed first order

Ask each company for a quote for **one disk**, with two disks as an optional
quantity comparison. This is a proposed quantity, not a confirmed preference.
The first material candidates are **0.020-inch clear PETG from Xometry** and
**0.030-inch clear polypropylene from SendCutSend**. Use the same disk geometry
for both quotes. This compares two supplier/material combinations; differences
in playback cannot be attributed to the supplier alone.

Generate the files from the repository root:

```bash
PYTHONPATH=src python3 -m symphonium_disc_maker.cli validate examples/pachelbel_sampler.json
PYTHONPATH=src python3 -m symphonium_disc_maker.cli dxf examples/pachelbel_sampler.json -o output/pachelbel_quote_only.dxf
PYTHONPATH=src python3 -m symphonium_disc_maker.cli svg examples/pachelbel_sampler.json -o output/pachelbel_sampler.svg
```

Upload only the DXF for cutting. The annotated SVG is a visual reference.
The DXF uses millimeters and contains one disk, with 143 rectangular drive cutouts
and 20 round music cutouts. Confirm the preview shows a **177.800 mm diameter**.
Thickness is a separate material selection; it is not encoded by this 2D file.

## Dimensions to confirm

Values below come from `geometry.json` unless stated otherwise.

| Feature | Inches | Millimeters |
| --- | ---: | ---: |
| Outside diameter | 7.000 | 177.800 |
| Original thickness | 0.020 | 0.508 |
| Center hole, rounded prototype nominal | 0.200 | 5.0800 |
| Metal center post, corrected trusted measurement | 0.1925 | 4.8895 |
| Each drive cutout, radial | 0.100 | 2.540 |
| Each drive cutout, tangential | 0.090 | 2.286 |
| Drive cutout center radius | 3.373 | 85.6742 |
| Music cutout diameter | 0.116 | 2.9464 |

Use **0.200 inch as the first-prototype center-hole nominal**. Clear upper and
opposed side edges in the original scan give approximately 0.198 inch,
consistent with the user's less certain 0.1995-inch inside-jaw reading of the
plastic hole. The corrected trusted metal-post measurement is **0.1925 inch**.
This resolves the earlier apparent mismatch; a retaining-head explanation is
unnecessary. The original handoffs retain the superseded values as history.

The prototype has **0.0075 inch (0.1905 mm) diametral clearance**, or 0.00375 inch
per side. This is smaller than the suppliers' published general cutting
tolerances below. Ask each supplier to confirm that the finished center hole
will clear the 4.8895 mm post; nominal preflight cannot establish finished fit.
See the [center-hole edge analysis](REFERENCE_CHECK.md#center-hole-edges-and-post-fit)
for calibration, boundary allowance and the annotated crop.

Both outputs represent the printed/top face. Chronological note holes are
laid out clockwise to play in order during the reported counterclockwise
physical rotation. The default 230-degree start angle is arbitrary. The
scan/audio direction result has also been independently reproduced locally;
the reference-check document describes its method and limits.

The generator rotates each drive opening with its polar position, so its sides
follow the radial/tangential axes. The local reference check confirms the
orientation and count. Comparing opposite quadrants separates the downward
scanner shadow from the hole dimensions: edge estimates are approximately
0.09909 inch radial and 0.08808 inch tangential. The current **0.100 × 0.090
inch** prototype nominals replace the earlier 0.095-inch square placeholder.
The calibrated scan scale is 601.754 pixels per inch; allow roughly 1–2 pixels
for optical boundary choice. Finished prototype fit determines whether these
nominals need adjustment.

Calculated from the corrected 143 radial/tangential rectangles:

- The smallest remaining bridge between drive cutouts is approximately
  **0.05602 in (1.4228 mm)**.
- The smallest distance from a drive cutout corner to the outside edge is
  approximately **0.07670 in (1.9483 mm)**.

These values replace the earlier bridge and edge distances computed for the
earlier drive-hole geometry.

These are nominal CAD distances, without cutting tolerances. The bridge is
particularly important when asking about manufacturability. Ask for achievable
cut tolerances and corner rounding as well as minimum hole and bridge sizes.
No automatic quote acceptance establishes mechanical fit in the Symphonium.

## SendCutSend material availability

SendCutSend currently lists laser-cut
[clear Mylar at 0.005 and 0.010 in](https://sendcutsend.com/materials/mylar-clear/)
and [clear polypropylene at 0.030 in](https://sendcutsend.com/materials/polypropylene/).
Neither matches the measured 0.020-inch original. Mylar at 0.010 inch is half
the original thickness; polypropylene at 0.030 inch is 50% thicker.
Their stiffness and mechanical behavior in this mechanism remain untested.

The intended SendCutSend experiment is one disk in 0.030-inch clear
polypropylene, subject to confirming clearance for the extra thickness.
Mylar is a thinner alternative, not the current first candidate. An exact
0.020-inch plastic option can also be discussed if polypropylene will not fit.

The published stock pages state a cutting tolerance of ±0.009 inch for these
two plastics. Ask how that applies to the small drive cutouts and thin bridges.
SendCutSend explains that its minimum hole, bridge, and hole-to-edge values
depend on the exact material and thickness in its
[preflight guidance](https://sendcutsend.com/blog/10-common-reasons-your-design-is-failing-sendcutsend-preflight/).

Use their [contact page](https://sendcutsend.com/contact/) for feasibility
questions, then the quote portal linked from their material pages. A price and
an accepted material/process have not been verified for this disk.

## Xometry material availability

Xometry's [standard sheet thickness table](https://www.xometry.com/sheet-cutting/standard-sheet-sizes/)
explicitly lists **clear PETG at 0.020 inch**. This matches the measured original
thickness and is the leading candidate for the Xometry prototype. It does not
establish the original polymer identity or prove mechanical compatibility.

Xometry's [sheet cutting standards](https://www.xometry.com/manufacturing-standards/)
give nominal top-face edge-to-edge tolerances of ±0.010 inch and warn that
holes at or below 0.100 inch diameter can exceed standard tolerances on the
top face because of piercing. The warning describes round holes; ask how
piercing affects the 0.100 × 0.090-inch rectangular drive cutouts as well. Confirm achievable
dimensions and corner rounding before accepting the quote.

Its [sheet cutting capability page](https://www.xometry.com/capabilities/sheet-cutting/)
also advertises automatic quotes for tolerances as tight as ±0.005 inch and
manual review for tighter requirements. This is a capability statement, not
confirmation for this thin PETG disk. Ask which tolerance is actually achievable
for the center opening, small drive cutouts and their positions.

Request a manual review of the material, thickness, bridges, and drive cutouts
if the instant quote does not offer an appropriate option. Xometry's
[quoting guidance](https://community.xometry.com/kb/articles/678-troubleshooting-common-quoting-issues)
says unsupported sheet gauges and custom materials can require manual review.
Ask the supplier to select a process that preserves the small cutouts and to
state any tooling charge separately.

## Draft inquiry for each company

Copy this into the supplier's inquiry form with the DXF attached after reviewing
the dimensions. It is a draft; it has not been sent. Add **"Please quote clear
PETG at 0.020 inch"** for Xometry, or **"Please quote clear polypropylene at
0.030 inch as a thickness experiment"** for SendCutSend.

> I am seeking a prototype quote for a replacement plastic music disk for a
> Mr. Christmas Animated Holiday Symphonium, model 140-24021. Please quote
> one piece, with an optional price for two. The original is 7.000 inches
> (177.800 mm) in diameter and approximately 0.020 inches (0.508 mm) thick.
> The original polymer is not yet identified. Can you offer thin plastic
> suitable for a disk that must remain flat while engaging drive pins and
> music pluckers? Please identify the polymer and actual stock thickness.
>
> The attached DXF is at 1:1 scale in millimeters. It contains 143 rectangular
> drive cutouts, nominally 2.540 mm radial × 2.286 mm tangential, and 20 round music cutouts,
> nominally 2.9464 mm in diameter. The narrowest bridge between drive
> cutouts is approximately 1.4228 mm. The drive openings follow the local
> radial/tangential axes. Please confirm these features are
> manufacturable, the cut tolerances and internal corner rounding, and
> whether the finished disk can be supplied flat with clean edges.
>
> The 5.0800 mm center hole is a rounded, scan-informed prototype nominal.
> The trusted metal-post measurement is 4.8895 mm (0.1925 inch), giving only
> 0.1905 mm (0.0075 inch) nominal diametral clearance. Please confirm finished-hole
> tolerances preserve clearance over that post. Please treat this file as a
> prototype feasibility and pricing request. Flag any required dimensional
> changes or material substitutions before cutting.
> Please include shipping and any setup or tooling fees in the quote.

## Before ordering and after delivery

1. Use the rounded 0.200-inch center hole and scan-derived 0.100 × 0.090-inch
   drive cutout nominals. The trusted metal post is 0.1925 inch.
2. Confirm material, thickness, feature limits, tolerances, quantity, and total
   price with each company. Regenerate the DXF if dimensions change.
3. Compare the quote preview with the original disk and pay for the agreed
   prototype only after those details are settled.
4. On receipt, check flatness, thickness, hole dimensions, and whether the
   hole clears the post and the disk seats like the original without forcing
   it. Confirm the top face and first test playback without a label.
5. Record at least two revolutions and identify each supplier/material.
   Follow `prototype_pack/recording_sequence.csv` to check all 20 tines.
   Attacks are 1.4063 seconds apart; acoustic decay may overlap. Use the
   recording to refine the pitch map and geometry, especially inferred track 20.

| Supplier | Material and thickness | Quantity | Delivered price | Quote status |
| --- | --- | --- | --- | --- |
| SendCutSend | Candidate: clear PP, 0.030 in | Proposed 1 | Not quoted | Not submitted |
| Xometry | Candidate: clear PETG, 0.020 in | Proposed 1 | Not quoted | Not submitted |

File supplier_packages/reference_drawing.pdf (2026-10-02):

2.540

2.286

# SYMPHONIUM MUSIC DISK - PROTOTYPE QUOTE

### Pachelbel 20-tine sampler | Printed/top-face view | All dimensions in mm

Reference drawing only. Manufacture from pachelbel_cut_mm.dxf at 1:1 scale.

DRIVE OPENING

Detail, enlarged

Long side: radial
Short side: tangential
Axes rotate with ring

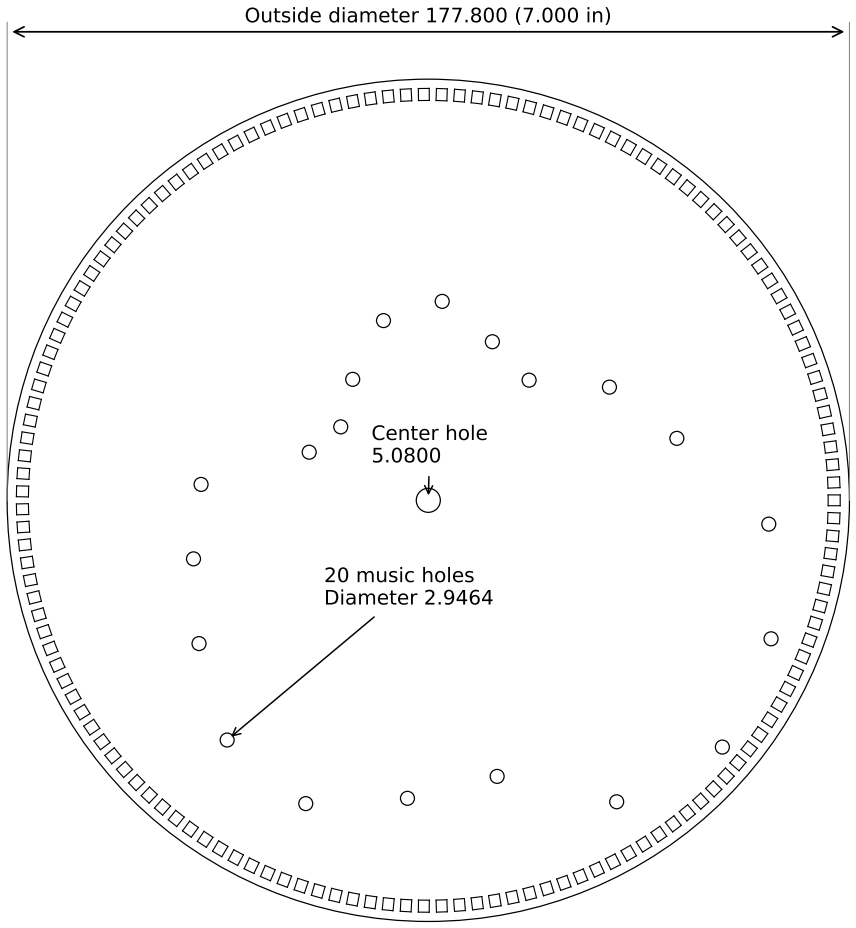
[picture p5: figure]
Outside diameter 177.800 (7.000 in); Center hole 5.0800; 20 music holes Diameter 2.9464

Drive openings | 143 rectangles, 2.540 radial x 2.286 tangential
Drive center radius | 85.6742; equal angular spacing
Minimum drive bridge | 1.4228
Minimum outer edge margin | 1.9483 at drive corner
Xometry material request | Clear PETG, 0.508 mm (0.020 in); original thickness reference
SendCutSend material request | Clear polypropylene, 0.762 mm (0.030 in); thickness experiment

### SUPPLIER CONFIRMATION REQUIRED BEFORE CUTTING

Center post: 4.8895 mm. Nominal diametral clearance: 0.1905 mm.
Confirm the minimum finished opening through the full thickness clears the post.
State achievable hole/position tolerances and corner rounding; propose any changes for review. Confirm stock thickness and flat, clean-edged delivery. Quantity: quote 1, optional price for 2. Dimensions are prototype nominals. This drawing does not impose an unverified +/- tolerance.

Cut-file SHA-256: ec4e174329df93d682abef2e0361f3df6db0b5136ccddd760fbc8de70f6110a4

Sheet 1 of 1 | Drawing scale: illustrative; do not measure this PDF | No quote submitted

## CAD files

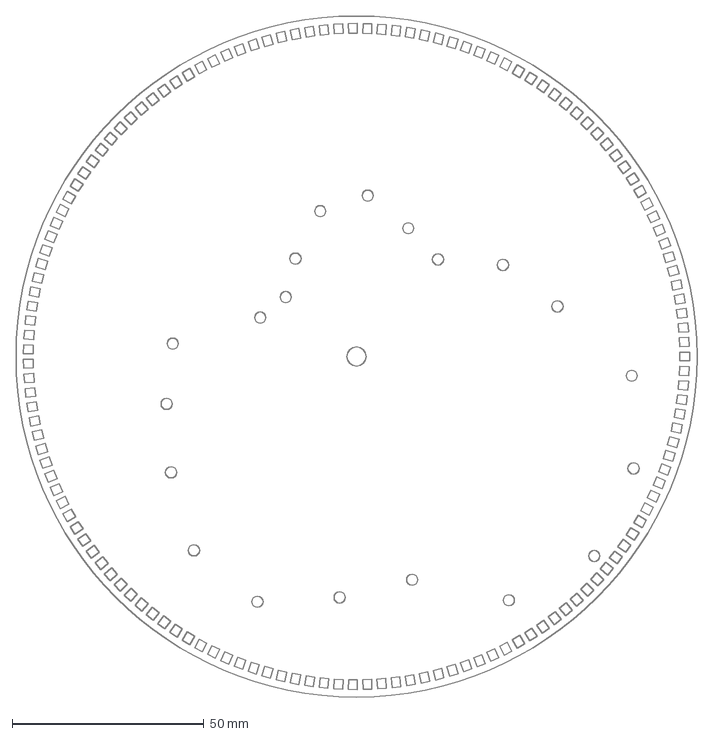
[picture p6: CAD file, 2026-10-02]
prototype_pack/pachelbel_cut_mm.dxf
177.8 x 177.8 mm

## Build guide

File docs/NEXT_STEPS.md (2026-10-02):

# Next steps: request quotes for prototype disks

Prepared October 2, 2026.

The files are ready for supplier feasibility review and pricing. No further
questions for the other AI, or new measurements from you, are needed before
requesting quotes. No request has been submitted and no order has been placed.

## Read this plan in VS Code

Open `docs/NEXT_STEPS.md` in VS Code. Use **Ctrl + Shift + V** for the Markdown
preview; the file and website links below are clickable there.

If you want to read it in the repository's WSL terminal instead, type:

```bash
cat docs/NEXT_STEPS.md
```

## 1. Find and extract the supplier packages

The packages are:

- [Xometry quote package](../supplier_packages/xometry_quote.zip)
- [SendCutSend quote package](../supplier_packages/sendcutsend_quote.zip)
- [Dimensioned reference drawing](../supplier_packages/reference_drawing.pdf)

To copy and extract the ZIPs, press **Windows + E** to open File Explorer.
Press **Ctrl + L**, paste this folder address, and press **Enter**:

```text
\\wsl.localhost\Ubuntu\home\rharris\git\symphonium-disc-maker\supplier_packages
```

The two files to use are:

```text
xometry_quote.zip
sendcutsend_quote.zip
```

Copy both ZIPs to your Windows Downloads folder. Right-click each copied ZIP
and choose **Extract All**. Keep the extracted folders separate because their
quote requests specify different materials.

Each extracted package contains:

- `pachelbel_cut_mm.dxf`: the manufacturing cutting file.
- `reference_drawing.pdf`: a dimensioned reference drawing.
- `quote_request.txt`: the request to send to that supplier; open it in Notepad.
- `README.txt`: short instructions for the package.
- `package_manifest.json`: file hashes for identifying this version; keep it
  with the package.

## 2. Request one prototype from each supplier

Use these proposed first requests:

| Supplier | Requested material | Quantity |
| --- | --- | --- |
| Xometry | Clear PETG, 0.020 inch thick | Quote one disk; optional price for two |
| SendCutSend | Clear polypropylene, 0.030 inch thick | Quote one disk; optional price for two |

The SendCutSend material is thicker than the 0.020-inch original disk and is a
thickness experiment. Its fit in the mechanism is not yet established.

Use these website links:

- [Xometry sheet cutting and quote entry](https://www.xometry.com/capabilities/sheet-cutting/)
- [SendCutSend contact / feasibility questions](https://sendcutsend.com/contact/)
- [SendCutSend polypropylene material / quote entry](https://sendcutsend.com/materials/polypropylene/)

Upload `pachelbel_cut_mm.dxf` as the manufacturing CAD file, using **millimeters
and 1:1 scale**. Supply `reference_drawing.pdf` as supporting material and
paste the contents of that supplier's `quote_request.txt` into its notes or
inquiry form. If the portal cannot offer the requested material or thickness,
ask for manual feasibility review rather than accepting a substitution.

The preview should show one disk with:

- **177.800 mm outside diameter** (7.000 inches).
- **5.0800 mm center opening** (0.200 inch).
- **143 rectangular drive openings** and **20 round music holes**.

The reference PDF is illustrative. Use the DXF for cutting; do not measure the
PDF to determine manufacturing dimensions.

## 3. Get the supplier's confirmations before paying

The quote requests already ask about these details, so you do not need to
write the technical questions yourself:

- Whether the small drive openings can be made at the specified dimensions,
  with suitable hole-location tolerances and corner rounding.
- Whether the finished center opening, through the full material thickness,
  will clear the trusted **0.1925-inch metal post** (4.8895 mm). Its nominal
  diametral clearance is only 0.0075 inch; general cutting tolerances alone
  do not establish fit.
- Actual material, stock thickness, flatness and clean edge condition.
- Price for the proposed quantity, shipping, and any setup or tooling fees.
- Any proposed dimensional or material changes, for review before cutting.

## 4. Bring the replies back to Codex

Save or copy each company's reply and quote, and provide it here before paying.
Include any proposed changes to material, thickness, dimensions or tolerances.
I can compare the two replies and revise the files if necessary.

After those details are settled, the next step is ordering the agreed
prototypes. On arrival, test the disks without labels first and record the
sampler playback to check all 20 tines.

## Optional: fit a paper label while waiting

Open the [label fitting PDF](../prototype_pack/label_fit_test.pdf). You can
also find it in this folder using Windows File Explorer:

```text
\\wsl.localhost\Ubuntu\home\rharris\git\symphonium-disc-maker\prototype_pack
```

Open `label_fit_test.pdf` and print it on plain US Letter paper at
**100% / actual size**, with **Fit** and **Shrink** disabled. Check the
one-inch ruler, then hand-cut one 1.50-inch label and its center opening.
Place it on the original disk and check that it covers no music or drive holes.

The Gazelle can wait until you are ready to connect and power it on. Supplier
quote preparation and this paper fitting test can proceed independently.

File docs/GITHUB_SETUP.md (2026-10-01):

# GitHub setup

Suggested repository name:

`symphonium-disc-maker`

Intended URL:

`https://github.com/rharriszzz/symphonium-disc-maker`

From the unpacked directory:

```bash
git init
git add .
git commit -m "Initial Symphonium disc generator"
git branch -M main
git remote add origin git@github.com:rharriszzz/symphonium-disc-maker.git
git push -u origin main
```

Create the empty repository on GitHub first, without adding a README or license,
because this starter archive already contains both.

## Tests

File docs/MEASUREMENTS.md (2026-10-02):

# Measurements and reverse-engineering notes

## Machine

Mr. Christmas Animated Holiday Symphonium, model 140-24021.

## User measurements

- Disc diameter: 7.000 in
- Disc thickness: 0.020 in
- Center-hole diameter, latest reading: 0.1995 in; user has lower confidence positioning the inside jaws in the small plastic hole
- Prototype center-hole nominal: 0.200 in, rounded from independent clear-edge scan fits of approximately 0.198 in
- Note-hole diameter: approximately 0.116 in
- Disc edge to outer edge of drive hole: approximately 0.0760 in
- Drive holes: approximately 0.09–0.10 in, initially described as square
- Metal center-post diameter: 0.1925 in; corrected user measurement, trusted by the user
- Approximate plucker-channel width: 0.040 in
- Innermost-to-outermost plucker geometry implies about 0.11792 in pitch

## Scan-derived observations

A 600 dpi scan of an original 7-inch disc established:

- 143 drive holes
- 145 note holes on the scanned *Unchained Melody* disc
- 19 occupied note rows on that disc
- row spacing approximately 0.118 in
- one additional outer track is consistent with the 20-tine mechanism

## Drive hole orientation and scan provenance

The October 1, 2026 [conversation handoff](CODEX_HANDOFF.md), sections 5 and 6,
reports analysis of all 143 drive-hole components in the original full-resolution
scan. The reported square orientations follow the local radial/tangential axes,
with a mean residual of roughly 1.6 degrees. Both exporters now use this
orientation. The earlier globally axis-aligned squares were incorrect.

The original scan is named `img20261001_00272891.png`, reportedly 5100 × 6600
pixels at approximately 600 dpi. The reported disc fit is centered at
(2396.453, 4361.565) pixels with radius 2104.615 pixels. These are handoff results,
not the local fit. The original image is now accessible from its Windows
location, and a separate local analysis is saved in
[the reference check](REFERENCE_CHECK.md). It confirms 143 drive holes, 145
music holes, and radial/tangential orientation, with approximately 1.60° mean
absolute orientation residual at the selected threshold.

That fitted diameter is 4209.231 pixels versus 4200 pixels for a 7.000-inch disk
at exactly 600 dpi, a difference of about 0.22%. The local fit uses a different
edge threshold and calibrates its 4212.277-pixel diameter to the measured
7.000 inches. Its overlay makes that calibration explicit.
Keep the original outside ordinary Git history if possible, with any derivative
and its calibration recorded separately.

Opposite-quadrant edge comparisons in the local reference check resolve the
size question beyond the initial bright-region mask. The scanner shadow stays
downward while the openings rotate. Edges across the shadow give approximately
**0.09909 inch radial × 0.08808 inch tangential**; opposite groups agree within
0.4 pixel. The openings appear slightly rectangular. `geometry.json` uses
rounded prototype nominals **0.100 inch radial × 0.090 inch tangential**,
replacing the earlier averaged 0.095-inch square. Optical boundary choice is
approximately 1–2 pixels, or 0.0017–0.0033 inch. See the paired crops and
method in [the reference check](REFERENCE_CHECK.md).

The drive tooth is reported to be smaller than the opening; deliberate
clearance should be preserved rather than sizing the opening to the tooth.

## Playback direction and layout angle

The [rotation and center-post follow-up](CODEX_FOLLOWUP_ROTATION_CENTERPOST.md)
reports that the user confirmed the scan shows the printed/top face and the
mechanism reads underneath. It also reports scan/audio correlation favoring
decreasing hole angle with increasing playback time. That result has
now also been checked independently against the original scan and M4A:
decreasing-angle chronological order scores about 3.89 times higher at the
nominal period and wins across all tested periods. Its inferred physical
rotation is counterclockwise when viewed from the top, or clockwise when
viewed from underneath. See [the local methods and limits](REFERENCE_CHECK.md).

Both exporters define the geometry as viewed from the printed/top face. Zero
degrees points right (+X), and positive polar angles are counterclockwise.
Chronological note holes therefore proceed clockwise:

```text
event angle = start angle - 360 * time / revolution seconds
```

SVG reflects Cartesian y to display the same physical geometry as DXF. Its
annotations use the same event angles as the holes. The default 230-degree
start angle is an arbitrary layout choice, not a measured reader angle or a
mechanical index. Changing it rotates the music pattern relative to the drive
ring while preserving relative note timing.

## Center hole and material fit

The user corrected the metal post to **0.1925 inch** and trusts that reading.
The latest original-hole reading is **0.1995 inch**, which the user considers
less reliable: positioning the inside jaws in a small plastic opening is harder
than measuring the metal post with the outside jaws. These
corrections supersede the earlier 0.2085-inch post reading and the treatment
of 0.196 inch as a settled measurement of the original hole.

The post is smaller than either hole value, resolving the apparent size
conflict. A wider retaining head or snap-fit explanation is no longer needed
to explain these measurements.

The [independent clear-edge scan check](REFERENCE_CHECK.md#center-hole-edges-and-post-fit)
fits the upper arc and opposed side arcs separately, excluding the downward
shadow. It gives approximately **0.198 inch**, with both scan-DPI and
outer-diameter calibrations recorded. The 0.1995-inch inside-jaw reading is
consistent with the scan's practical optical boundary allowance; no additional
caliper readings are needed to prepare these files.

Use **0.200 inch as the rounded first-prototype nominal**, replacing 0.196 inch.
This is a deliberate prototype dimension, not a claim that the scan resolves
the original to four decimal places. It gives **0.0075 inch diametral clearance**,
or **0.00375 inch per side**, over the trusted metal post. The 0.1995-inch
inside-jaw reading would give 0.0070 inch diametral clearance.

Ask the supplier whether finished-hole tolerances preserve clearance over the
0.1925-inch post, then check that the manufactured disk seats without forcing
it. The missing unobstructed post photograph is no longer needed to resolve
the dimensional question. The original handoffs remain historical records.

## Original supporting files

Place local originals in `reference_material/`, whose contents are ignored by
Git, or provide an accessible external path. Useful evidence includes:

- `img20261001_00272891.png`: original 600 dpi scan, preserving DPI metadata.
- `116 E Main St 15.m4a`: original mechanism recording.
- The scan/audio analysis scripts and any detected-hole tables, if retained.
- Mechanism photographs showing the center post and disk seating position.

The original scan and recording are now accessible at the external paths in
[the reference check](REFERENCE_CHECK.md). They have not been copied into Git.
The response package supplied four 640 × 480 photographs, now copied to
`reference_material/IMG_3359.jpeg` through `IMG_3362.jpeg` (ignored by Git).
Direct inspection shows an installed disk, a loose disk, the comb/plucker
assembly, and the drive mechanism respectively. These do not match several
photo descriptions in [the supplied response](CHATGPT_RESPONSE.md); in
particular `IMG_3361.jpeg` does not show the center post. No unobstructed
center-post seating-profile photograph has been identified in this package.
The response and its [aligned drive profiles](data/aligned_drive_profiles.csv)
are retained in Git. The earlier analysis scripts have not been supplied.
The reference-check overlay uses the actual scan; other disk previews in
`output/` are generated CAD artwork.

## Working pitch map

Provisional, inner to outer:

C4 D4 E4 F4 G4 A4 B4
C5 D5 E5 F5 G5 A5 B5
C6 D6 E6 F6 G6 A6

An independent search over 22 consecutive-white-key maps starting from C2
through C5 ranks **C4** first with two FFT sizes, fundamental-only and
harmonic-weighted evidence, and separate first/second-revolution checks.
See [the comparison and its assumptions](REFERENCE_CHECK.md).

The evidence supports the global C4–G6 occupied-track mapping, rather than
independently measuring each tine. Tracks 18–19 have only one reference attack
each. Track 20's A6 is inferred: the original disk never plays it. Keep the
working map and test every track on the sampler. Its 1.4063-second attack gaps
may still contain overlapping acoustic decay, so it is not guaranteed to
produce a clean isolated sample for each tine.

## Timing

A recording of the original disc gave approximately 28.126 seconds per revolution.

## Important distinction

The disc encodes a note **attack**. A larger or longer hole is not assumed to
encode musical duration. The tine's acoustic decay supplies the perceived duration.

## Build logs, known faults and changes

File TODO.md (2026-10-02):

# TODO

## Geometry
- [x] Record corrected trusted 0.1925-inch metal post and less certain 0.1995-inch original-hole reading.
- [x] Independently measure clear center-hole arcs in the scan; select 0.200-inch rounded prototype nominal.
- [ ] Verify finished 0.200-inch prototype hole clears the 0.1925-inch post; confirm supplier tolerances.
- [x] Resolve drive-hole prototype dimensions from opposite-quadrant scan edges: 0.100 inch radial × 0.090 inch tangential.
- [x] Apply handoff scan result: rotate drive squares with local radial/tangential axes.
- [x] Reproduce scan analysis locally and check a calibrated geometry overlay.
- [x] Apply follow-up convention: top-face CAD, clockwise chronological holes, arbitrary 230-degree start phase.
- [x] Independently reproduce reported scan/audio playback-direction result.
- [x] Independently check the supplied 143-hole ensemble and outer-boundary ellipse results.
- [x] Compare 22 pitch maps with fundamental/harmonic evidence and separate revolutions; mark track 20 inferred.
- [ ] Test the scan-derived drive-hole dimensions on a manufactured prototype.
- [ ] Confirm absolute center radius of track 20 after first manufactured sampler.
- [ ] Record exact disc material and stiffness if identified.

## Arranging
- [ ] MIDI import.
- [ ] MusicXML import.
- [ ] Octave folding / nearest-playable-note helpers.
- [ ] Repeated-note reset warnings.
- [ ] Chord-density warnings.
- [ ] Loop-boundary preview.

## Output
- [x] Separate label artwork and cutting outlines; reject labels covering note holes.
- [x] Physical-size label PDFs with a calibration ruler.
- [ ] Disk PDF preview generation.
- [ ] Optional construction guides.
- [ ] Optional label registration marks for BossKut/Silhouette/Cricut.
- [x] Generate SendCutSend/Xometry prototype pack with nominal preflight, source hashes and supplier drafts.
- [x] Package separate supplier quote ZIPs with an audited cutting DXF, dimensioned reference drawing and tailored requests.

## Prototype orders and labels
- [x] Research supplier material options and save draft inquiries in docs/ORDERING.md.
- [ ] Quote Xometry 0.020-inch PETG and SendCutSend 0.030-inch PP; confirm 0.05602-inch bridges and drive-cutout tolerances.
- [ ] Obtain and compare quotes for one prototype from each supplier.
- [ ] Order prototypes after confirming geometry and material.
- [x] Research the Gazelle CUTOK driver requirement in docs/LABELS.md.
- [x] Establish Gazelle OS preference: Windows 11 first, Mac fallback; exclude Windows 10.
- [x] Import latest discoveries; close photo/drive interpretation questions and remove CUTOK URLs from the active setup workflow.
- [x] Inspect Windows host: Windows 11 Home x64, SCAL 6.085 already installed, existing installer signature valid; no present cutter candidate found.
- [ ] Inspect Gazelle enumeration on Windows 11, evaluate the SCAL trial and request Craft Edge's driver if missing; use Apple Silicon Mac fallback if needed.
- [ ] Fit a plain-paper 1.50-inch center label and confirm the center opening.
- [ ] Verify print-to-cut alignment before using printed adhesive stock.

## Audio
- [ ] Cut and record 20-tine sampler disc.
- [ ] Build isolated real-tine sample bank.
- [ ] Add realistic preview renderer.

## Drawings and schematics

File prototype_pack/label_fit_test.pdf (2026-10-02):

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

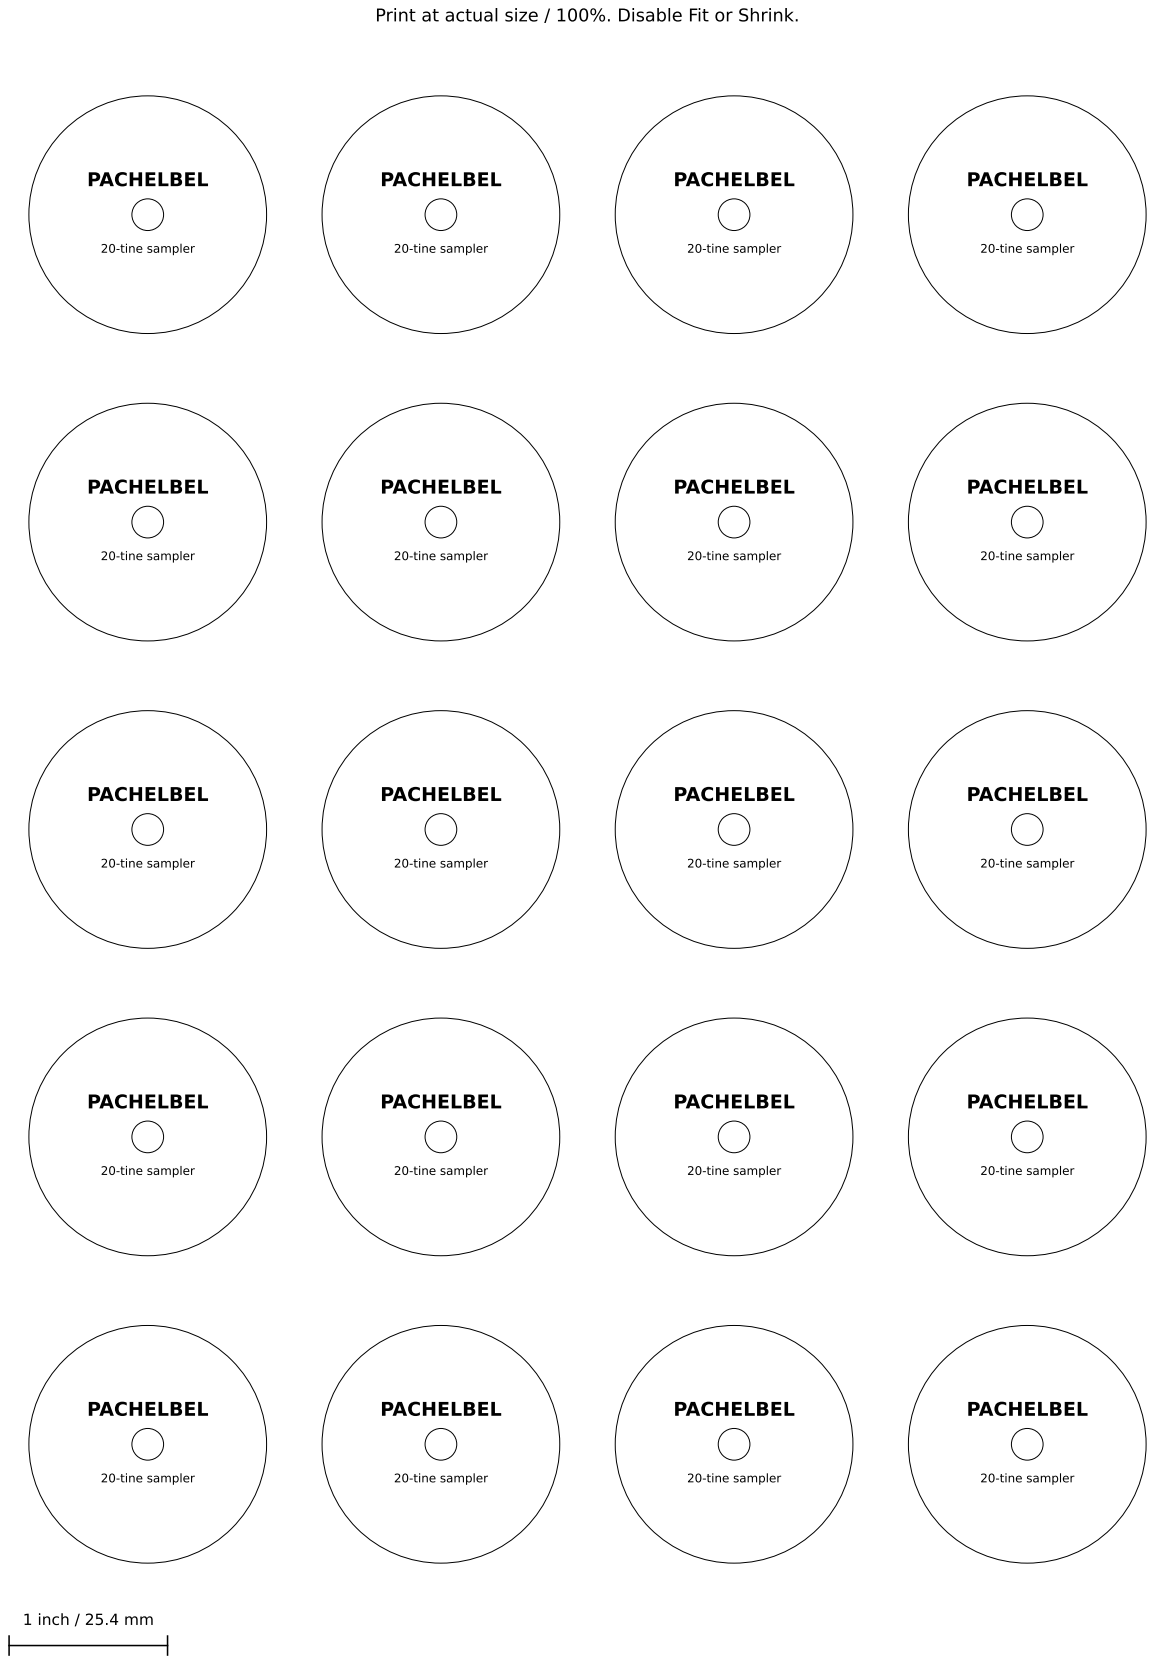
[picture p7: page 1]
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

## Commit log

2026-10-02 Correct scan-derived disk geometry and prepare prototype and label workflows
2026-10-02 Import ChatGPT response and supporting profiles; flag photo discrepancies
    [aligned_drive_profiles.csv]
2026-10-02 Verify reference geometry and pitches; prepare prototype pack and printable labels
    [pachelbel_cut_mm.dxf, recording_sequence.csv]
2026-10-02 Resolve center-post measurements and measure clear scan edges
    [pachelbel_cut_mm.dxf]
